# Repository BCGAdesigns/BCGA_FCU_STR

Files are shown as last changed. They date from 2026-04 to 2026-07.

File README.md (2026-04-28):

# BCGA FCU — Open-source HPA Fire Control Unit






> Open-source Fire Control Unit for airsoft HPA replicas. WiFi-native configuration, dual-solenoid support, 4 independent cycle timings, and Hall trigger with automatic EMI noise calibration — unique on the market.

> 🇧🇷 Leia em português: [LEIA-ME.md](LEIA-ME.md)

---

## What is the BCGA FCU?

The **BCGA FCU** is a digital Fire Control Unit for airsoft HPA (High Pressure Air) replicas, built around the ESP32-C3 SuperMini. It drives the solenoid(s) that replace the mechanical trigger of an HPA engine and lets you tune each phase of the firing cycle from any browser over WiFi — no app required.

Two hardware variants share the same firmware and web UI:

- **STR** (Starter) — perfboard / THT build, easily sourced components, ideal for makers and hobbyists learning HPA electronics.
- **PRO** — commercial SMD PCB with battery monitoring, LiPo kill latch, dedicated WiFi button and onboard buzzer.

Both variants support **S8PA** (1-solenoid engines — PolarStar JACK / F1, Wolverine INFERNO, GATE PULSAR S) and **D8PA** (2-solenoid engines — PolarStar F2 / Fusion Engine, GATE PULSAR D) per slot. You pick the engine type per profile — the UI adapts automatically.

This project is designed, manufactured and maintained by **[BCGA Airsoft](https://bcgaairsoft.com)** in Brazil. It is **open-source under GPL v3** — you can audit, modify, manufacture and sell, as long as derivatives keep the same license and credit the original project.

---

## Why BCGA FCU?

Compared to commercial FCUs (PolarStar REV3, Wolverine BLINC, GATE TITAN II, Gorilla FCU), the BCGA FCU has concrete advantages — and a few honest limitations. This section is factual; the full side-by-side tables are in [`MANUAL_EN.md`](MANUAL_EN.md) section 16.

### Where the BCGA FCU wins

1. **Native WiFi vs Bluetooth.** Configure from any browser on any device — iOS, Android, PC, Linux. No app install, no pairing, no vendor lock-in. TITAN II (BLE 5.2) and BLINC require proprietary apps.

2. **4 independent timings (DN/DR/DP/DB).** Each phase of the D8PA cycle has its own parameter. Feeding (DN), sealing (DR), FPS (DP) and post-shot debounce (DB) tune independently without trade-offs. Commercial FCUs top out at 3 user-facing timings (REV3 in dual-solenoid mode: dP/dN/dr) or a single dwell on single-solenoid setups — none expose a dedicated post-shot debounce.

3. **Automatic Hall trigger EMI noise calibration.** The only FCU on the market with a routine that fires the solenoids dry and measures the EMI kick on the ADC, widening the Hall deadband automatically. Eliminates ghost fires without sacrificing trigger sensitivity.

4. **3 complete independent slots.** Each slot stores everything — engine type, all 4 timings, selector config, individual Hall calibrations, flags. Switching slots = full game-profile switch.

5. **Open-source, GPL v3.** All code is public. Audit, modify, compile and flash without depending on proprietary firmware or a vendor app. TITAN II, BLINC and REV3 are fully closed.

6. **Hall trigger with 2-point calibration + automatic hysteresis.** Captures the exact fire point and computes a hysteresis band from real measurements — not fixed values. No mechanical potentiometer.

7. **3-position Hall selector.** SAFE/SEMI/FULL via a wear-free Hall sensor. Each position freely configurable to any mode (including BURST 2/3/4).

8. **Drastically lower BOM cost.** The STR can be built from easily sourced THT parts for a fraction of any commercial Bluetooth FCU.

9. **Live theoretical ROF in the UI.** The web panel shows maximum achievable ROF as you move the sliders — no chrono needed for a first-pass estimate.

10. **Per-slot S8PA/D8PA switching in software.** Each of the 3 slots independently stores the engine type — flip a slot between S8PA and D8PA directly from the web UI, no hardware change. Commercial FCUs that cover both architectures (TITAN II with PULSAR S/D, Gorilla) do it through separate dedicated cable harnesses per engine, not per-slot software switching.

### Honest limitations

- **No binary trigger.** Not implemented. Available on Wolverine BLINC, GATE TITAN II and Gorilla FCU.
- **No tournament lock with password.** Workaround: set Semi ROF high and ROF limit low before an event. Available on TITAN II (Expert) and Gorilla.
- **No automatic battery cut-off.** The firmware enters lockout mode (firing disabled, continuous beep) when the battery reaches critical level on the PRO variant, but you must physically disconnect the battery to preserve charge. The STR variant has no battery voltage read at all — use with caution on 2S/3S packs without external protection.
- **Battery drains while plugged.** The voltage regulators on the PRO board draw ~12-18mA continuously even when the ESP32 is sleeping. A 1000mAh pack will be fully discharged in 2-3 days if left connected. Always disconnect the battery between sessions.
- **First pull after deep sleep wakes via reboot.** After 60 min of idle, the next pull wakes the MCU through a full reboot — the **second** pull actually fires.

---

## Hardware specifications

| Item | Value |
|---|---|
| MCU | ESP32-C3 SuperMini |
| MOSFETs | IRLZ44NPBF (TO-220, THT) |
| Main connector | JST 8-pin (A1501WR-S-8P) — native to the D8PA ecosystem |
| Operating voltage | 7.4 V — 11.1 V (2S/3S LiPo) |
| Engine types | S8PA (1 solenoid) / D8PA (2 solenoids) |
| Fire modes | SAFE / SEMI / FULL / BURST 2 / BURST 3 / BURST 4 |
| Configuration | Web UI over WiFi AP (192.168.4.1) |
| Deep sleep | 60 min idle → ESP32 <10 µA, total board ~12-18 mA (regulators) |
| Inactivity alarm | 60 min idle → 6 cycles of 5min beep + 1h sleep, then permanent sleep |
| Battery management (PRO) | Lockout mode at critical voltage (no auto cut-off — physical disconnect required) |
| License | GPL v3 |

---

## Repository structure

```
BCGA_FCU_STR/
├── MotherBoard/              # Main board (MOBO) — BOM, CPL, GERBER, SCH, STEP
├── DaugtherBoard_BCGA/       # Daughterboard A — BCGA engine (S8PA or D8PA)
├── Gearbox_DaughterBoard/    # Daughterboard B — V2 standard (AEG conversion)
├── firmware/
│   ├── BCGA_FCU_STR/         # Arduino sketch — Starter variant
│   └── BCGA_FCU_PRO/         # Arduino sketch — Pro variant
├── MANUAL_EN.md / .pdf       # English manual (this README links here)
├── MANUAL_PT.md / .pdf       # Portuguese manual
├── README.md                 # English readme (this file)
├── LEIA-ME.md                # Portuguese readme
└── LICENSE                   # GPL v3
```

Each board folder contains: `BOM` (xlsx), `CPL` (xlsx), `GERBER` (zip), `SCH` (pdf) and `STEP` (3D model).

---

## How to use

1. Get the hardware — either buy a pre-assembled board from [bcgaairsoft.com/fcu/str](https://bcgaairsoft.com/fcu/str) / [fcu/pro](https://bcgaairsoft.com/fcu/pro), or clone this repo and build your own (see next section).
2. Flash the matching firmware from `firmware/BCGA_FCU_STR/` or `firmware/BCGA_FCU_PRO/` via the Arduino IDE. Target board: **ESP32-C3 Dev Module**, with **USB CDC On Boot = Enabled**.
3. On first boot, the FCU brings up a WiFi AP.
   - Default SSID: `BCGA_FCU_STR` or `BCGA_FCU_PRO`
   - Default password: `12345678`
4. Connect your phone/laptop to the AP. A captive page opens at `http://192.168.4.1`.
5. Configure the 3 slots: engine type (S8PA/D8PA), timings (DN/DR/DP/DB), selector, flags. The full tuning workflow is in [`MANUAL_EN.md`](MANUAL_EN.md).

To re-open the AP later:
- **STR** — hold the trigger for 5 s during the first 5 s after boot; OR pull the trigger 5 times in SAFE within 3 s.
- **PRO** — press the dedicated WiFi button; or use the same gestures as STR.

The AP shuts off automatically after 10 min of web inactivity.

---

## Build your own

1. Upload the chosen board's `GERBER` zip to a PCB fab (JLCPCB, PCBWay, etc.).
2. Order the components from the matching `BOM`. Most parts are available on [LCSC](https://www.lcsc.com/).
3. Solder following the `SCH` (schematic).
4. Flash the firmware from `firmware/BCGA_FCU_{STR,PRO}/` via the Arduino IDE.
5. Calibrate the Hall trigger and selector from the web UI (sections 7 and 8 of the manual).

> ⚠️ **STR** requires basic THT soldering skills (TO-220 MOSFETs, through-hole headers). **PRO** requires basic SMD soldering skills. For a plug-and-play board, buy the pre-assembled version at [bcgaairsoft.com](https://bcgaairsoft.com).

---

## License

[**GPL v3**](LICENSE). You can manufacture, modify, sell and distribute freely, as long as derivatives keep the same license and credit the original project. Closed-source forks are not permitted.

---

## Links

- **Product pages:** [bcgaairsoft.com/fcu/str](https://bcgaairsoft.com/fcu/str) · [bcgaairsoft.com/fcu/pro](https://bcgaairsoft.com/fcu/pro)
- **Main site:** [bcgaairsoft.com](https://bcgaairsoft.com)
- **User manual (English):** [MANUAL_EN.md](MANUAL_EN.md) · [PDF](MANUAL_EN.pdf)
- **User manual (Portuguese):** [MANUAL_PT.md](MANUAL_PT.md) · [PDF](MANUAL_PT.pdf)
- **Issues and support:** [GitHub Issues](https://github.com/BCGAdesigns/BCGA_FCU_STR/issues)

---

**BCGA Airsoft** — [bcgaairsoft.com](https://bcgaairsoft.com)

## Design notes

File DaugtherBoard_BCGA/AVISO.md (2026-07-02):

# AVISO / NOTICE

PT: Erro encontrado em uma trilha da PCB. Correção em andamento. Arquivos atualizados (Gerber, BOM, CPL, esquematico, STEP) serao enviados em breve. Nao fabrique nem monte com os arquivos atuais.

EN: Error found in one PCB trace. Fix in progress. Updated files (Gerber, BOM, CPL, schematic, STEP) coming soon. Do not fabricate or assemble with current files.

Data / Date: 2026-07-01

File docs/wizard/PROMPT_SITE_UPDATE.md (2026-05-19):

# Prompt para Claude Code — atualizar o wizard em bcgaairsoft.com

Cole o conteúdo abaixo numa nova sessão do Claude Code aberta no repositório do site (`~/ClaudeCode/projeto/bcgaairsoft/bcgaairsoft`). Ele descreve o estado atual do firmware da BCGA FCU, as mudanças recentes que precisam refletir no wizard online, e a nova tela inicial de 3 menus.

---

## Contexto

Você está trabalhando no site React da BCGA Airsoft (`bcgaairsoft.com`). O site hospeda um **Setup Wizard** público que ajuda o usuário a planejar a configuração da FCU **antes** de flashar e tunar no airsoft.

A FCU em si tem o repositório separado em `~/ClaudeCode/projeto/bcgaairsoft/BCGA_FCU_STR`. Lá existem dois pontos de referência que valem consultar:

- `docs/wizard/index.html` + `wizard.css` + `wizard.js` — versão standalone original do wizard (5 steps), serve de base visual e estrutural.
- `firmware/web_ui_dev/index_str.html`, `index_pro.html`, `style.css`, `app.js` — UI **runtime** servida pelo ESP no AP (estado atual após várias rodadas de iteração). É a fonte de verdade dos campos/labels/help texts.

O wizard online deve ficar **alinhado com o runtime** (mesmas siglas, mesmos defaults, mesmas faixas), mas mantém o foco em ensinar/planejar — ele não escreve no ESP.

## Tarefa

1. **Encontrar o wizard atual no site** (provavelmente em `src/pages/wizard` ou similar — explore antes de tocar).
2. **Reescrever a tela inicial** para 3 menus (detalhe abaixo).
3. **Reaproveitar o wizard de configuração existente** dentro do menu "Quero configurar do zero".
4. **Adicionar dois novos modos** ("Aprender" e "Resolver problema").
5. **Atualizar todos os campos, defaults, faixas e textos de ajuda** para casar com o estado atual do firmware (lista completa abaixo).

## Tela inicial — 3 menus

Depois do header (logo + nome BCGA FCU · Setup Wizard + toggle PT/EN), o usuário vê 3 cards grandes clicáveis:

1. **Quero apenas aprender** → entra no modo educacional. Tour guiado explicando uma a uma cada função da FCU. Sem perguntas, só conteúdo + navegação Próximo/Anterior. Lista de tópicos sugerida na seção "Modo Aprender" abaixo.

2. **Quero configurar do zero** → entra no wizard atual de 5 steps. Esta é a versão hoje em produção (engine pick → FPS alvo → FPS atingido? → fine-tune → summary). Mantenha o fluxo, mas atualize os campos/labels/textos de ajuda conforme a seção "Mudanças no firmware" abaixo.

3. **Quero resolver um problema** → modo troubleshooting. Usuário descreve o sintoma (input de texto livre OU lista de sintomas comuns clicáveis — escolha o que fizer mais sentido para o site). O wizard responde com diagnóstico + onde mexer. Catálogo de sintomas → soluções na seção "Modo Resolver problema" abaixo.

Adicione um botão de "Voltar ao início" persistente em qualquer ponto dos 3 fluxos.

## Mudanças no firmware desde a última versão do wizard

Atualize TODOS os pontos do wizard atual (modo "Configurar do zero") para refletir o que segue:

### Renomeação de seções

| Antes | Agora |
|---|---|
| "Tipo de disparo" | **Engine** |
| "Entrada" | **Funções** |
| (não existia) | **Avançado** |
| (não existia) | **Estatísticas** |

### Cards do Engine

- "Single Solenoid S8PA" — subtítulo "1 solenoid (Jack, Backdraft)"
- "Dual Solenoid D8PA" — subtítulo "2 solenoids (F2, Pulsar)"

### Defaults validados em campo (use estes nos exemplos do wizard)

- DN = 24 ms (antes 18)
- DR = 24 ms (antes 26)
- DP = 24 ms (antes 80; o "max-tune-down" foi abandonado)
- DB = **5 unidades** (= 0,5 ms; faixa nova: 5–150 unidades = 0,5–15 ms)
- IS = 30 s (antes 60)
- IP = 1 multiplicador (NOVO conceito — explicado abaixo)

### Faixas atuais

| Campo | Faixa | Unidade | Default |
|---|---|---|---|
| DN | 2–80 | ms | 24 |
| DR | 2–80 | ms | 24 |
| DP | 2–80 | ms | 24 |
| DB | 5–150 | unidades de 0,1 ms (= 0,5–15 ms) | 5 |
| ROF max | 0–50 | rps (0 = sem limite) | 0 |
| Semi Max ROF | 0–500 | ms | 0 |
| IS | 0–600 | segundos | 30 |
| IP | 0–5 | multiplicador de DP | 1 |

### Anti-stiction (NOVO — IS + IP)

Conceito que NÃO existia no wizard antigo. Adicione um bloco explicando:

- **Stiction** = o o-ring do poppet "gruda" depois da arma ficar parada por um tempo. Resultado: primeiro tiro depois de tempo parado sai com FPS baixo / sem cadência.
- **IS (Inter-Stiction Idle)** — tempo em segundos de inatividade até o boost ser armado. Padrão 30 s.
- **IP (Inter-Stiction Pulse)** — multiplicador de DP. Cada incremento adiciona um DP inteiro ao próximo tiro pós-idle.
  - DP = 24 ms, IP = 1 → primeiro tiro pós-idle dispara com DP = 48 ms (24+24)
  - DP = 24 ms, IP = 2 → primeiro tiro pós-idle dispara com DP = 72 ms (24+24+24)
  - IP = 0 → desabilitado.
- **Quando ajustar:** se o primeiro tiro depois de ficar 30+ s parado sair fraco, suba o IP em 1 e teste no chrono. Tiros subsequentes voltam ao DP normal automaticamente.

### Tipo de seletor (Selector input)

Antes só dava pra mexer em selPos1/2/3. Agora a UI tem um dropdown explícito **"Selector input: Microswitch / Hall (analog)"**, espelhando o do gatilho. A seção de Calibração do Seletor só aparece quando Hall é escolhido. 3-pos continua forçando Hall (e trava o dropdown).

### "Inverter gatilho" sumiu

Campo `invertTrig` continua no firmware mas **não aparece mais na UI**. Não mencione no wizard.

### Idioma padrão = EN

Page-load default agora é EN (antes era BR). Ainda tem toggle BR/EN. Mantenha o toggle no wizard online.

### Estatísticas (somente runtime — NÃO precisa no wizard online)

A FCU agora exibe stats em tempo real (Tiros sessão, Tiros total, Bateria no PRO, próxima lubrificação a cada 10k tiros). É só pra você saber que existe — não é parte do fluxo de planejamento.

### Config LOCK e Factory Reset (somente runtime)

Mesma situação. A FCU tem agora trava de configuração via senha + reset de fábrica por gesture (gatilho 30 s no boot, no PRO + botão WiFi). Mencione brevemente no modo "Aprender" mas não no fluxo de configuração.

## Modo Aprender — sugestão de capítulos

Cada capítulo é uma página/card com explicação curta (~150 palavras), 1 imagem ou diagrama opcional, e botões Anterior/Próximo:

1. **O que é uma FCU** — diferença entre AEG eletrônica e HPA, qual papel a FCU faz no airsoft HPA.
2. **Engines: S8PA vs D8PA** — single vs dual solenoid, exemplos (Jack/Backdraft vs F2/Pulsar/Wolverine), implicação prática (D8PA tem nozzle independente, alimentação mais consistente).
3. **Ciclo de disparo D8PA** — animação ou diagrama: pulso SOL2 (DN) → espera (DR) → pulso SOL1 (DP) → espera pós-tiro (DB) → repete.
4. **Ciclo de disparo S8PA** — só pulso SOL1 (DP) → espera (DR) → repete. DN e DB inativos.
5. **DN — Nozzle Dwell** — para que serve, sintomas de DN curto (falha de alimentação) vs longo (desperdício de gás). Faixa, padrão.
6. **DR — Dwell Rest** — em D8PA: espera entre nozzle e poppet pra mola vedar o bucking. Em S8PA: descanso entre tiros. Faixa, padrão.
7. **DP — Dwell Poppet** — duração do pulso de tiro. Sintomas: DP curto = FPS baixo; DP longo = desperdício de gás + risco de tiro duplo. Tunar no chrono.
8. **DB — Trigger Debounce** — pausa entre ciclos pra BB sair do cano antes do próximo tiro (D8PA). Faixa nova 5–150 unidades de 0,1 ms.
9. **ROF max e ROF teórico** — diferença entre limite e teórico, como o teórico é calculado.
10. **Anti-stiction (IS + IP)** — bloco completo conforme descrito acima.
11. **Seletor: Pos1/Pos2/Pos3 e modos de fogo** — Safe/Semi/Full/Burst2/3/4.
12. **Microswitch vs Hall** — quando escolher cada um, calibração necessária para Hall.
13. **Calibração Hall** — fluxo de noise + posições (gatilho solto/pressionado, ou 3 posições do seletor).
14. **Modo silencioso e MOSFET swap** — quando usar.
15. **Config LOCK e Factory Reset por gesture** — como travar configuração pra evitar mexida acidental, como recuperar se esquecer (gesto físico no boot).
16. **Estatísticas em tempo real** — bateria, tiros, próxima lubrificação a cada 10k.

Pode reagrupar ou cortar capítulos conforme fizer sentido visualmente. Mantenha foco em "tuning-first" — toda explicação de timing leva ao "o que aumentar/diminuir pra qual sintoma".

## Modo Resolver problema — catálogo de sintomas

Sugestão de input: lista de sintomas clicáveis (mais robusto que parsing de texto livre numa primeira versão). Cada item leva a uma tela com:
- Diagnóstico provável
- Setting a verificar
- Range/passo sugerido pra ajuste
- Avisos

Catálogo mínimo:

| Sintoma | Causa provável | Onde mexer |
|---|---|---|
| Arma não dispara | Bateria descarregada / seletor em SAFE / fire mode SAFE em todas as posições | Conferir bateria · Verificar selPos1/2/3 |
| FPS baixo geral | DP curto / regulador baixo / vazamento na engine | Subir DP (testar no chrono) · Conferir pressão · Inspecionar o-rings |
| Primeiro tiro fraco após arma parada | Stiction do o-ring do poppet | **Habilitar IP (=1) com IS=30s**; subir IP até estabilizar |
| FPS inconsistente tiro a tiro | Vazamento intermitente / regulador instável / BB mass inconsistente | Trocar BBs · Inspecionar regulador · Conferir vazamentos |
| Falha de alimentação (BB não chega) | DN muito curto (D8PA) / nozzle gasto / mola fraca | Subir DN · Trocar nozzle · Trocar mola da torre |
| Cadência muito alta (incontrolável) | DR curto / DB curto / sem ROF cap | Subir DR · Subir DB · Definir ROF max |
| Cadência muito baixa | Soma de timings alta | Reduzir DN, DR, DB pelo menor valor que ainda funcione |
| Tiros duplos em SEMI | Trigger ricochete / Hall mal calibrado | Habilitar Semi Max ROF (tente 100ms) · Recalibrar Hall com noise |
| Cadência sobe e desce em FULL | ROF cap zerado + bateria caindo | Definir ROF max abaixo do pico real |
| Esqueci a senha do Config LOCK | Sem recuperação digital | Factory reset por gesture: gatilho 30s no boot (STR) ou gatilho + botão WiFi 30s (PRO) |
| Seletor Hall lê posição errada | Calibração de seletor desatualizada | Calibração do seletor (3 posições) — fluxo Hall |
| Gatilho Hall dispara sozinho | Ruído eletromagnético do solenoide | Calibração de ruído ANTES da calibração do gatilho |

Adicione mais conforme fizer sentido. Para cada solução, link pra explicação no modo "Aprender" se houver.

## Estilo

- Mantenha a paleta atual do site bcgaairsoft.com (memory note: "site is the visual source of truth — pull palette/fonts from there"). Não invente cores novas.
- O wizard runtime usa accent verde (`#8aab47` STR / `#00bcd4` PRO). O site provavelmente já tem palette própria — siga o do site.
- Toggle PT/EN persistente no header. Idioma default = EN.

## Entregáveis

1. Tela inicial 3-menus integrada ao wizard.
2. Modo "Aprender" com pelo menos 12 dos 16 capítulos sugeridos.
3. Modo "Resolver problema" com pelo menos 8 dos 12 sintomas do catálogo.
4. Modo "Configurar do zero" atualizado com todos os campos/defaults/textos novos.
5. README curto explicando como rodar localmente e onde editar conteúdo (capítulos do Aprender e catálogo de Resolver), porque eles vão crescer.

## O que NÃO fazer

- Não copiar o `firmware/web_ui_dev/` direto — aquilo é UI de configuração runtime, este wizard tem propósito diferente (pré-flash, educacional).
- Não inventar campos que não existam no firmware.
- Não escrever em `firmware/` neste repo — você está no repo do site.
- Não traduzir nomes técnicos consagrados (DN, DR, DP, DB, IS, IP, S8PA, D8PA, F2, Jack, Pulsar) — só os textos de ajuda em volta.

Quando terminar, mostre URL local pra eu testar e abra um PR descrevendo as mudanças.

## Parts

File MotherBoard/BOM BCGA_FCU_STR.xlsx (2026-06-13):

No. | Quantity | Comment | Designator | Footprint | Value | Manufacturer Part | Manufacturer | Supplier Part | Supplier
1 | 2 | 100nF | C1,C2 | CAP-TH_L5.0-W2.5-P5.00-D1.0 | 100nF | CC1H104MC1FD3F6C10MF | Dersonic(德尔创) | C254085 | LCSC
2 | 2 | 470uF | C3,C4 | CAP-TH_BD10.0-P5.00-D1.0-FD | 470uF | ERS1VM471G16OT | AISHI(艾华集团) | C106703 | LCSC
3 | 2 | 100nF | C5,C6 | CAP-TH_L5.8-W3.6-P5.0-D0.6 | 100nF | 178MU0002 | KNSCHA(科尼盛) | C5632426 | LCSC
4 | 1 | A1501WR-S-8P | CN1 | CONN-TH_A1501WR-S-8P |  | A1501WR-S-8P | CJT(长江连接器) | C225173 | LCSC
5 | 2 | 1N5819 | D1,D2 | DO-41_BD2.4-L4.7-P8.70-D0.9-RD |  | 1N5819 | DOWO(东沃) | C27636129 | LCSC
6 | 2 | IRLZ44NPBF-VB | Q2,Q3 | TO-220-3_L10.0-W4.5-P2.54-L-2 |  | IRLZ44NPBF-VB | VBsemi(微碧半导体) | C20755022 | LCSC
7 | 2 | 10kΩ | R1,R2 | RES-TH_BD2.3-L6.5-P10.50-D0.5 | 10kΩ | MF1/4W-10KΩ±1% T | CCO(千志电子) | C119347 | LCSC
8 | 2 | 100Ω | R3,R4 | RES-TH_BD2.3-L6.5-P10.50-D0.5 | 100Ω | MF1/4W-100Ω±1% T | CCO(千志电子) | C119304 | LCSC
9 | 2 | 1kΩ | R5,R6 | RES-TH_BD2.3-L6.5-P10.50-D0.5 | 1kΩ | MF1/4W-1KΩ±1%T52 | 华星机电 | C713997 | LCSC
10 | 2 | Test-Point | TP1,TP2 | Test-Point-0.5mm
11 | 1 | Mini DC-DC Boost Step Up Converter | U1 | MINI DC-DC BOOST STEP UP CONVERTER |  |  |  |  | LCSC
12 | 1 | ESP32-C3 OLED | U6 | ESP32-C3 OLED

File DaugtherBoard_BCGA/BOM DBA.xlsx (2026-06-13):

No. | Quantity | Comment | Designator | Footprint | Value | Manufacturer Part | Manufacturer | Supplier Part | Supplier
1 | 2 | 100nF | C1,C2 | C0603 | 100nF | CC0603KRX7R9BB104 | YAGEO(国巨) | C14663 | LCSC
2 | 1 | A1501WR-S-8P | CN1 | CONN-TH_A1501WR-S-8P |  | A1501WR-S-8P | CJT(长江连接器) | C225173 | LCSC
3 | 3 | S2B-ZR-SM2-TF(LF)(SN) | CN6,CN10,CN11 | CONN-SMD_2P-P1.50_S2B-ZR-SM2-TF-LF-SN |  | S2B-ZR-SM2-TF(LF)(SN) | JST | C5306678 | LCSC
4 | 2 | 1kΩ | R1,R2 | R1206 | 1kΩ | 1206W4F1001T5E | UNI-ROYAL(厚声) | C4410 | LCSC
5 | 2 | SS39ET | U1,U2 | SOT-23-3_L2.9-W1.3-P1.90-LS2.4-BR |  | SS39ET | Honeywell(霍尼韦尔) | C126669 | LCSC

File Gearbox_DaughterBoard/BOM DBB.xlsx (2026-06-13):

No. | Quantity | Comment | Designator | Footprint | Value | Manufacturer Part | Manufacturer | Supplier Part | Supplier
1 | 2 | 100nF | C2,C3 | C0402 | 100nF | CL05B104KB54PNC | SAMSUNG(三星) | C307331 | LCSC
2 | 4 | S2B-ZR-SM2-TF(LF)(SN) | CN6,CN9,CN10,CN11 | CONN-SMD_2P-P1.50_S2B-ZR-SM2-TF-LF-SN |  | S2B-ZR-SM2-TF(LF)(SN) | JST | C5306678 | LCSC
3 | 1 | A1501WR-S-8P | CN12 | CONN-TH_A1501WR-S-8P |  | A1501WR-S-8P | CJT(长江连接器) | C225173 | LCSC
4 | 2 | 1kΩ | R2,R3 | R0402 | 1kΩ | 0402WGF1001TCE | UNI-ROYAL(厚声) | C11702 | LCSC
5 | 2 | SS39ET | U2,U3 | SOT-23-3_L2.9-W1.3-P1.90-LS2.4-BR |  | SS39ET | Honeywell(霍尼韦尔) | C126669 | LCSC

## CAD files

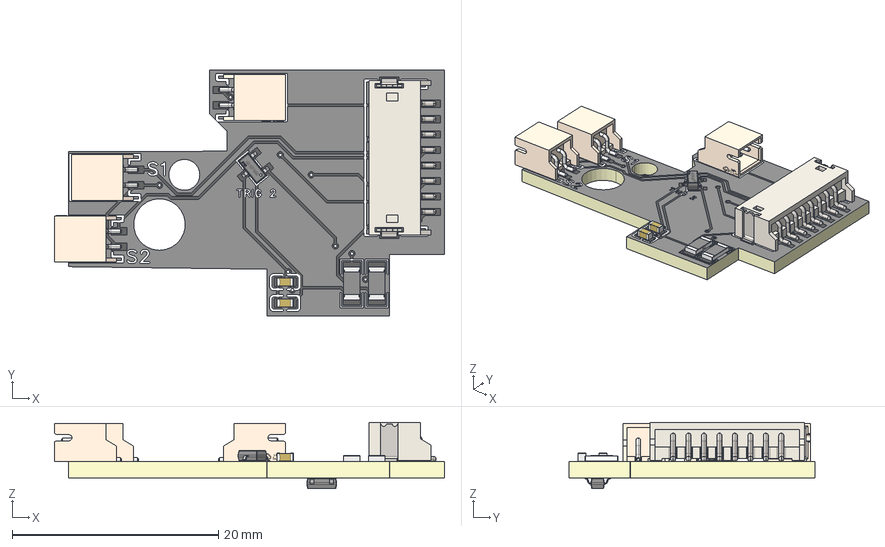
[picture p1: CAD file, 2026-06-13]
Assembly_STEP/DBA.step
37.8 x 23.9 x 6.45 mm
Board~A52b
TopCopper~A52b x 19
BottomCopper~A52b x 10
TopSilkscreen~A52b x 46
BottomSilkscreen~A52b x 89
TopFpcStiffener~A52b
BottomFpcStiffener~A52b
SOT-23-3_L2.9-W1.3-P1.90-LS2.4-BR~SOT-23-3P_ L2.9-W1.3-H1.0-LS2.4-P0.95~A52b x 2
C0603~C0603_L1.6-W0.8-H0.8~A52b x 2
R1206~R1206_L3.2-W1.6-H0.6~A52b x 2
CONN-TH_A1501WR-S-8P~CONN-TH_A1501WR-S-8P~A52b
CONN-SMD_2P-P1.50_S2B-ZR-SM2-TF-LF-SN~CONN-SMD_2P-P1.50_ S2B-ZR-SM2-TF-LF-SN~A52b x 3

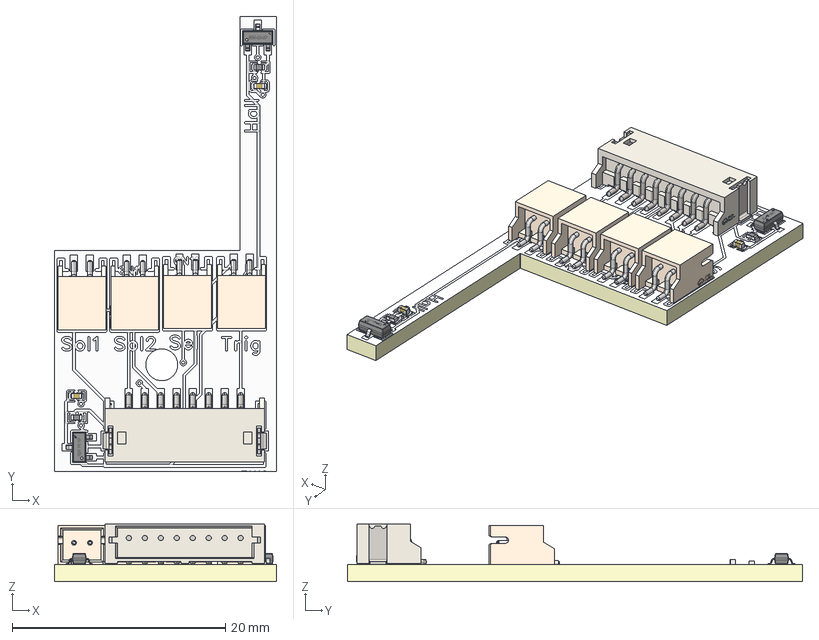
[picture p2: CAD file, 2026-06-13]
Gearbox_DaughterBoard/STEP DBB.step
20.9 x 42.7 x 5.41 mm
Board~KRs3
TopCopper~KRs3 x 19
BottomCopper~KRs3 x 5
TopSilkscreen~KRs3 x 71
BottomSilkscreen~KRs3
TopFpcStiffener~KRs3
BottomFpcStiffener~KRs3
C0402~C0402_L1.0-W0.5-H0.5~KRs3 x 2
CONN-SMD_2P-P1.50_S2B-ZR-SM2-TF-LF-SN~CONN-SMD_2P-P1.50_ S2B-ZR-SM2-TF-LF-SN~KRs3 x 4
CONN-TH_A1501WR-S-8P~CONN-TH_A1501WR-S-8P~KRs3
SOT-23-3_L2.9-W1.3-P1.90-LS2.4-BR~SOT-23-3P_ L2.9-W1.3-H1.0-LS2.4-P0.95~KRs3 x 2
R0402~R0402_L1.0-W0.5-H0.4~KRs3 x 2

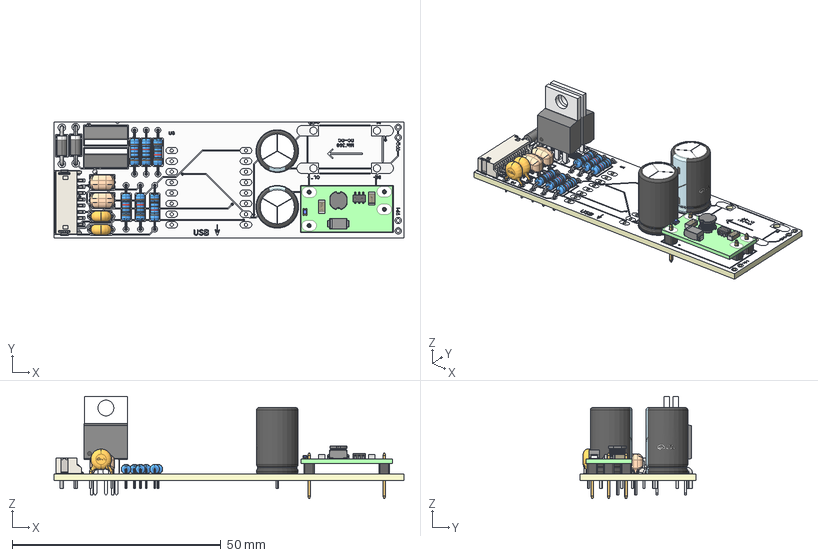
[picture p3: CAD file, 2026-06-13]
MotherBoard/STEP BCGA_FCU_STR.step
83.8 x 27.8 x 24.5 mm
Board~LMB1
TopCopper~LMB1 x 54
BottomCopper~LMB1 x 41
TopSilkscreen~LMB1 x 134
BottomSilkscreen~LMB1 x 34
TopFpcStiffener~LMB1
BottomFpcStiffener~LMB1
RES-TH_BD2.3-L6.5-P10.50-D0.5~RES-TH_D2.3-L6.5-P10.50~QHUY x 6
CONN-TH_A1501WR-S-8P~CONN-TH_A1501WR-S-8P~HQcQ
CAP-TH_BD10.0-P5.00-D1.0-FD~CAP-TH_D10.0-H16.0-P5.00~eAUI x 2
DO-41_BD2.4-L4.7-P8.70-D0.9-RD~DO-41_D2.4-L4.7-P8.70~po2f x 2
TO-220-3_L10.0-W4.5-P2.54-L-2~TO-220-3_L10.0-W4.5-P2.54-L-2~1yOL x 2
CAP-TH_L5.0-W2.5-P5.00-D1.0~CAP-TH_BD5.0-W2.5-P5.08~cXeb x 2
CAP-TH_L5.8-W3.6-P5.0-D0.6~CAP-TH_L5.8-W3.6-P5.0-D0.6~0Ine x 2
MINI DC-DC BOOST STEP UP CONVERTER~mini_dc_dc_PIN~Bhf9 x 11

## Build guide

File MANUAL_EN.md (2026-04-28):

# BCGA FCU — User Manual (EN)

Open-source firmware for the ESP32-C3 SuperMini. Two variants: **STR** (Starter, perfboard) and **PRO** (commercial product). The web UI and firing logic are nearly identical — differences are listed at the end.

This manual is practical: each section leads with **what to tweak to get what result**.

> 🇧🇷 Versão em português: [MANUAL_PT.md](./MANUAL_PT.md)

---

## Table of contents

1. [Understand the FCU in 1 minute](#1-understand-the-fcu-in-1-minute)
2. [Quick start — reach target FPS first](#2-quick-start--reach-target-fps-first)
3. [The 4 timings — tuning guide](#3-the-4-timings--tuning-guide)
4. [Recommended tuning workflow](#4-recommended-tuning-workflow)
5. [Firing type: S8PA vs D8PA](#5-firing-type-s8pa-vs-d8pa)
6. [Selector — 2 or 3 positions](#6-selector--2-or-3-positions)
7. [Hall trigger — step-by-step calibration](#7-hall-trigger--step-by-step-calibration)
8. [Hall selector — step-by-step calibration](#8-hall-selector--step-by-step-calibration)
9. [First use and web panel access](#9-first-use-and-web-panel-access)
10. [Slots](#10-slots)
11. [Useful flags (invert trigger, swap MOS, silent)](#11-useful-flags)
12. [Limit rate of fire (ROF limit and Semi ROF)](#12-limit-rate-of-fire)
13. [Diagnostics and WiFi](#13-diagnostics-and-wifi)
14. [Deep sleep, inactivity alarm and debug mode](#14-deep-sleep-inactivity-alarm-and-debug-mode)
15. [STR vs PRO differences](#15-str-vs-pro-differences)
16. [BCGA FCU vs commercial FCUs](#16-bcga-fcu-vs-commercial-fcus)

---

## 1. Understand the FCU in 1 minute

The FCU drives **1 or 2 solenoids** that replace the mechanical trigger of an HPA engine. For each shot it sends electrically calibrated pulses to the solenoids, in the correct order, with the correct waits between them. Tuning = adjusting those pulses for your specific setup (pressure, bucking, BB mass).

- **S8PA** (1 solenoid): PolarStar JACK / F1, Wolverine INFERNO, GATE PULSAR S, or any other 1-solenoid HPA engine. Only the poppet is driven.
- **D8PA** (2 solenoids): PolarStar F2 / Fusion Engine, GATE PULSAR D, or any other 2-solenoid HPA engine. Nozzle and poppet driven separately.

---

## 2. Quick start — reach target FPS first

New to the BCGA FCU? Before anything else, hit your target FPS. The rest of the tuning only makes sense once the chrono is where you want it. The 4 timings (DN/DR/DP/DB) are fully explained in section 3 — for this first pass you only touch **DP** (the poppet dwell slider) and the regulator.

1. **Set the regulator to 100 psi.** Default starting pressure for most D8PA setups.
2. **Keep the default timings** (`DN=18 / DR=26 / DP=25 / DB=100`). They ship loaded.
3. **Fire over a chrono.** Is the FPS (or joule) on target?
   - **Yes** → skip straight to section 4 and tune feeding, sealing and accuracy.
   - **No, too low** → step 4.
4. **Push DP to the slider maximum** (80 ms). Chrono again.
   - **FPS jumped to target** → lower DP step-by-step until FPS starts to drop, then add 1–2 ms back. That's your minimum efficient DP. Go to section 4.
   - **FPS still below target** → step 5.
5. **Raise the regulator to 110 psi.** Chrono again.
   - **On target** → lower DP until you find the minimum that holds target FPS. Go to section 4.
   - **Still low** → raise to **120 psi** and chrono again.
6. Once target FPS is stable, **go to section 4** and tune DN (feeding), DR (sealing) and DB (accuracy) in that order.

> **Principle:** FPS is driven mostly by **air pressure × DP**. The other 3 timings shape how the cycle *behaves* (feeding, sealing, accuracy, ROF) — they don't add FPS. Nail FPS first with DP/pressure, tune everything else after.

---

## 3. The 4 timings — tuning guide

The FCU exposes **4 independent timings** that map directly to each physical phase of the firing cycle: **DN**, **DR**, **DP**, **DB**. The page shows the theoretical ROF live as you move the sliders.

> **Note on units:** DN, DR and DP are in **milliseconds** (range 2–80 ms). **DB** (Trigger Debounce) uses **units** — 1 unit = 0.1 ms, range 20–800 units (= 2–80 ms). This aligns DB with the firmware's internal 0.1 ms timing resolution.

### DN — Nozzle Dwell (D8PA only)

Length of the **nozzle (SOL2)** pulse. This is how long the nozzle stays open for the BB to drop into the chamber.

| If DN increases | If DN decreases |
|---|---|
| ✅ easier feeding (heavy BBs, low pressure, cold shot) | ✅ saves air, prevents double-feed |
| ❌ **risk of double-feed** (2 BBs drop) | ❌ empty shots / inconsistent feeding if the return spring is slow |
| ❌ more nozzle wear | ❌ may not seal before DP fires |

**Rule of thumb:** decrease DN until you start getting empty shots, then add 1–2 ms margin.

### DR — Return / Rest

- **In D8PA**: wait between the nozzle pulse and the poppet pulse. Time for the nozzle to return and the **bucking to seal on the BB**.
- **In S8PA**: inter-shot rest.

| If DR increases | If DR decreases |
|---|---|
| ✅ consistent sealing → **stable FPS** | ✅ **higher ROF** |
| ✅ less shot-to-shot spread | ❌ poppet fires before seal → weak shot / low and variable FPS |
| ❌ lower ROF | ❌ BBs dropping past an open nozzle = double / bad pickup |

**Rule of thumb:** raise DR until the chrono stops oscillating under fast SEMI.

### DP — Poppet Dwell (the shot)

Length of the **poppet (SOL1)** pulse. This is how long air can flow through the nozzle pushing the BB.

| If DP increases | If DP decreases |
|---|---|
| ✅ **higher FPS** (more air behind the BB) | ✅ saves air (more shots per bottle/mag) |
| ❌ air waste after BB has left | ✅ higher ROF (valve closes fast) |
| ❌ may delay poppet recycle | ❌ **FPS below target**, weak shot |

**Rule of thumb:** with a chrono, tune DP up to your target FPS. Anything more just wastes air.

### DB — Trigger Debounce (D8PA only)

Wait after the poppet closes, before the trigger can re-arm the next cycle. Physically, this is the time needed for the **BB to clear the barrel** and the bucking to recover.

**Unit:** 1 unit = 0.1 ms. **Range:** 20–800 units (2–80 ms). **Default:** 100 units (10 ms).

| Units | Equivalent ms |
|---:|---:|
| 20  | 2.0  |
| 50  | 5.0  |
| 100 | 10.0 |
| 200 | 20.0 |
| 800 | 80.0 |

| If DB increases | If DB decreases |
|---|---|
| ✅ **better accuracy** (BB has left before the next nozzle opens) | ✅ **higher ROF** |
| ✅ bucking recovers undisturbed | ❌ BB still in the barrel when the next nozzle pulses → **flyers / inconsistent FPS** |
| ❌ lower ROF | ❌ reduced bucking life |

**Rule of thumb:** full-auto on a 20 m target. If flyers appear, bump DB by 20 units (2 ms) at a time.

### Defaults (generic D8PA, 110 psi, 0.28 g BB)

```
DN = 18 ms    DR = 26 ms    DP = 25 ms    DB = 100 units (10 ms)
```

Safe starting point. Tune from there.

---

## 4. Recommended tuning workflow

Follow this order — each step depends on the previous one being stable. Assumes you already hit your target FPS per section 2.

1. **Feeding (DN)** — slow SEMI. Lower DN until you get empty shots. Add 2 ms back.
2. **Sealing (DR)** — fast SEMI. If chrono wobbles, raise DR 2 ms at a time.
3. **FPS (DP)** — with chrono, raise DP to hit target FPS. Don't go higher.
4. **Accuracy (DB, D8PA only)** — full-auto on a target. If flyers, raise DB by 20 units.
5. **Cadence (ROF limit)** — optional. Caps maximum ROF independently of timings.
6. **Anti-spam (Semi ROF)** — optional. Minimum time between SEMI pulls.

> ⚠️ Always verify with a chrono. FPS drifts with bottle temperature / air level.

---

## 5. Firing type: S8PA vs D8PA

Chosen per slot in the first section of the panel.

- **S8PA** — only the poppet is pulsed. Cycle: `DP → DR → repeat`. Use with PolarStar JACK / F1, Wolverine INFERNO, GATE PULSAR S, or any 1-solenoid HPA engine. The DN, DB, MOS swap fields and the SOL 2 test button are hidden.
- **D8PA** — separate nozzle + poppet. Cycle: `DN → DR → DP → DB → repeat`. Use with PolarStar F2 / Fusion Engine, GATE PULSAR D, or any 2-solenoid system.

---

## 6. Selector — 2 or 3 positions

Enabling "3 positions" **requires a Hall selector** (a microswitch can only distinguish 2 states). Enabling it reveals Pos 3 in the UI.

Each position is assigned to a mode **independently**:

| Mode | Behavior |
|---|---|
| **SAFE** | Trigger pull does nothing. Mode-change beeps still play. |
| **SEMI** | One shot per pull. Honors Semi ROF if configured. |
| **FULL** | Fires while the trigger is held. |
| **BURST 2 / 3 / 4** | Fires 2/3/4 rounds per pull, even if trigger is released. |

Common examples:
- **2-position**: Pos 1 = SAFE, Pos 2 = SEMI *(or Pos 1 = SEMI, Pos 2 = FULL)*
- **3-position**: Pos 1 = SAFE, Pos 2 = SEMI, Pos 3 = FULL

---

## 7. Hall trigger — step-by-step calibration

Use Hall for a **wear-free trigger** with an **adjustable fire point**.

**Expected hardware:** linear Hall sensor (DRV5055 or similar) powered from 3.3 V, output wired to **PIN_TRIG** (GPIO 0 on both variants). Magnet on the trigger lever.

### 7.1 Mode selection

**Input** section → "Trigger type" → **Hall** → **Save**.

### 7.2 Quick calibration (single-point)

Covers most cases — 30 seconds.

1. In the **Sensitivity** section, pull the trigger **to the exact fire point you want** and hold.
2. Click **Capture point**.
3. The FCU reads the ADC and builds a symmetric hysteresis band around that value.
4. Save the slot.

Fires before reaching the point → capture at a deeper pull.
Won't fire even at full pull → capture at a shallower pull.

### 7.3 Full calibration (maximum precision)

In the **Trigger calibration** section:

1. **Noise calibration**
   - FCU fires **a full cycle without a BB** sampling the ADC during the solenoid pulses.
   - Measures EMI noise and **widens the deadband automatically**.
   - Prevents ghost fires caused by the MOSFETs' own switching kick.
   - ⚠️ **Run with the gearbox assembled and bottle connected** — noise depends on physical setup.

2. **Capture Released**
   - Trigger fully released → **Capture Released**.

3. **Capture Pressed**
   - Trigger fully pulled → **Capture Pressed**.

4. FCU computes a central threshold and a hysteresis band based on both points + measured noise.

5. **Save slot**.

### Hall trigger tuning

| Symptom | Likely cause | Fix |
|---|---|---|
| Ghost fires | Solenoid EMI bigger than deadband | Re-run noise calibration |
| Fires before fire point | Threshold too low | Recapture at a deeper pull point |
| Won't fire even at full pull | Threshold too high or magnet too far | Recapture, or move magnet closer |
| Flickers at threshold | Hysteresis band too narrow | Use full calibration instead of single-point |

---

## 8. Hall selector — step-by-step calibration

A Hall selector enables **3 physical positions** (classic SAFE/SEMI/FULL) or just more reliable 2-position reading.

**Expected hardware:** linear Hall sensor on the gearbox body, magnet on the selector plate. Output wired to **PIN_SEL** (GPIO 1).

### 8.1 Mode selection

**Input** section → "Selector type" → **Hall** → check "3 positions" if applicable → **Save**.

### 8.2 Calibration

**Selector calibration** section:

1. **Noise calibration** (optional but recommended) — same principle as the trigger.
2. Rotate selector to **Pos 1** → **Capture Pos 1**.
3. Rotate to **Pos 2** → **Capture Pos 2**.
4. (if 3-pos) Rotate to **Pos 3** → **Capture Pos 3**.
5. FCU computes thresholds between each pair of samples.
6. **Save slot**.

### 8.3 Assign modes

Under **Selector → Pos 1/2/3 Mode**, choose a firing mode per position. These fields apply regardless of input type (digital or Hall).

---

## 9. First use and web panel access

### First-boot

On first power-up (or after flashing a build that bumped the schema), NVS is re-initialized with defaults. Two long beeps (BOOT + READY) confirm first-boot; subsequent power-ups only play BOOT.

**Initial defaults:**

- 3 slots named `Slot 1`, `Slot 2`, `Slot 3`
- D8PA, 2-pos, Pos1=SEMI, Pos2=FULL
- Digital trigger (microswitch, active-LOW)
- Timings `DN=18 ms / DR=26 ms / DP=25 ms / DB=100 units (10 ms)`
- SSID = `BCGA_FCU_STR` or `BCGA_FCU_PRO`
- WiFi password = `12345678`

### Open the panel

Connect your phone/laptop to the AP and open any URL — the captive DNS redirects to the panel. Fixed address: `http://192.168.4.1`.

**Turn the AP on:**

| Variant | Gestures |
|---|---|
| **STR** | Hold the trigger for 5 s during the first 5 s after boot; OR 5 trigger pulls in SAFE within 3 s |
| **PRO** | Dedicated WiFi button; OR the same gestures above |

AP shuts off automatically after **10 min of web inactivity** (3 beeps).

---

## 10. Slots

3 independent slots. Each one holds **everything**: firing type (S8PA/D8PA), timings, selector, Hall calibrations, flags. Switch via the buttons at the top of the page.

The FCU remembers the last slot used and returns to it after reboot.

**Typical use:**
- Slot 1 = your main setup
- Slot 2 = aggressive tune (higher ROF, tighter DR)
- Slot 3 = backup / test

---

## 11. Useful flags

- **Invert trigger** — check if your microswitch is active-HIGH (rare).
- **Swap MOS** (D8PA only) — swaps SOL1↔SOL2 **in software**. Use if you soldered them backwards and don't want to desolder.
- **Silent mode** — mutes beeps only *during firing*. Mode-change beep still plays.

---

## 12. Limit rate of fire

### ROF limit (rounds/sec)

Global ceiling. If your timings allow 25 rps but you want 15 rps, set `15`. A delay is inserted automatically between shots.

- `0` = unlimited (ROF determined purely by the timings)
- Too low = FCU ignores your FULL pull until the limit allows the next shot

### Semi ROF (ms)

Cooldown **between SEMI pulls**. Prevents trigger spam (fast finger).

- `0` = disabled
- `150 ms` = caps at ~6 SEMI pulls/sec
- Does not affect FULL/BURST

---

## 13. Diagnostics and WiFi

### MOS test

- **Test MOS 1** — pulses MOSFET 1 for 2 s.
- **Test MOS 2** — pulses MOSFET 2 for 2 s (honors `Swap MOS`).

Use with a multimeter, LED, or solenoid to verify wiring.

> Refuses if the FCU is actively firing.

### Buzzer test

Plays each beep type. Useful to learn the sounds before a game. On STR the piezo is not populated by default; the code still runs but stays silent unless you add one to PIN_BUZZER.

### Change WiFi password

**WiFi** section → new password (min **8 characters**) → **Save**. Persists in NVS. Only resets on factory reset.

### Factory reset

Two ways:
1. Flash a build that bumps `STORAGE_INIT_VERSION` (NVS is wiped on next boot automatically).
2. If your build exposes **Advanced → Factory reset** on the panel.

---

## 14. Deep sleep, inactivity alarm and debug mode

### Inactivity alarm (NEW)

After **60 minutes without any user activity** (trigger pull, WiFi button press, selector change, or web UI interaction), the FCU enters an alarm sequence designed to grab your attention before sleeping:

- **6 alarm cycles**, each consisting of:
  - 5 minutes of short beeps every 30 seconds
  - Then 1 hour of deep sleep
  - Then wake and start the next cycle
- After all 6 cycles complete (~6 hours total), the FCU enters **permanent deep sleep**
- **Any activity resets the counter** and returns to normal operation

This protects against forgetting the FCU powered on, but **does not preserve the battery indefinitely** — see below.

### Deep sleep behavior

When the FCU enters deep sleep:
- ESP32-C3 draws **<10 µA**
- The voltage regulators on the PRO board (MP2315 buck, MT3608 boost, AMS1117 LDO) **continue drawing ~12-18 mA** as long as the battery is connected
- Total board draw in deep sleep: ~12-18 mA (regulators only)

A 1000 mAh battery will fully discharge in **2-3 days** if left connected, even if the ESP32 is sleeping.

> ⚠️ **The only way to truly preserve the battery between sessions is to physically disconnect it.**

### Wake-up

After deep sleep, the next trigger pull **wakes the MCU via full reboot** — the second pull is the one that actually fires.

### Debug mode (5 min)

For bench testing, edit `firmware/BCGA_FCU_{STR,PRO}/config.h` and uncomment:

```c
#define DEEP_SLEEP_DEBUG
```

Inactivity timeout drops from 60 min to 5 min. **Re-comment before shipping to production.**

### Battery lockout (PRO only)

The PRO variant monitors battery voltage and protects against deep discharge through **lockout mode** (not automatic cut-off — see below).

**Thresholds (per cell):**
- **Low warning**: 3.5 V/cell — single beep every 10 seconds
- **Critical**: 3.2 V/cell — single beep every 5 seconds
- **Cut (lockout)**: 3.0 V/cell — firing blocked, beep every 5 seconds

When lockout is triggered:
1. Firing is permanently disabled until reboot (battery reconnect)
2. Beep alert sounds every 5 seconds
3. After ~30 minutes of beeping (360 cycles), FCU enters permanent deep sleep
4. **Battery is not cut off** — you must physically disconnect to prevent further discharge

> ⚠️ **The PRO variant V2.1 does NOT have automatic battery cut-off.** Earlier versions (V2.0 and earlier) had a kill latch circuit that physically disconnected the battery — this was removed in V2.1 to simplify the circuit and eliminate a bootstrap reliability issue. The lockout mode + audible alarm is the new protection mechanism, but it relies on the user disconnecting the battery.

---

## 15. STR vs PRO differences

| Feature | STR | PRO |
|---|:---:|:---:|
| S8PA (1 solenoid) | ✅ | ✅ |
| D8PA (2 solenoids) | ✅ | ✅ |
| All modes (SAFE/SEMI/FULL/BURST2-4) | ✅ | ✅ |
| 3-pos Hall selector | ✅ | ✅ |
| Full Hall calibration | ✅ | ✅ |
| Web panel + AP gesture opening | ✅ | ✅ |
| 60 min deep sleep | ✅ | ✅ |
| Inactivity alarm (6 cycles → permanent sleep) | ✅ | ✅ |
| **Battery voltage read** | ❌ | ✅ |
| **Battery lockout** (firing block at critical V) | ❌ | ✅ |
| **Kill latch** (LiPo deep-discharge protection) | ❌ | ❌ (V2.1: lockout) |
| **Dedicated WiFi button** | ❌ | ✅ |
| **Onboard buzzer** | ❌ | ✅ |

---

## 16. BCGA FCU vs commercial FCUs

This section compares the BCGA FCU to the main commercial FCUs in the airsoft HPA market (PolarStar REV3, Wolverine BLINC, GATE TITAN II, Gorilla FCU). It is factual and includes both advantages and gaps.

### 16.1 Where the BCGA FCU wins

1. **Native WiFi vs Bluetooth.** Configure from any browser on any device — iOS, Android, PC, Linux, anything that opens a web page. No app install, no pairing, no vendor lock-in. TITAN II (BLE 5.2), BLINC and Gorilla all require proprietary apps.

2. **4 independent timings (DN/DR/DP/DB).** Each phase of the D8PA cycle has its own parameter. Feeding (DN), sealing (DR), FPS (DP) and post-shot debounce (DB) are tuned independently without trade-offs. Commercial FCUs top out at 3 user-facing timings (REV3 in dual-solenoid mode: dP/dN/dr) or a single dwell on single-solenoid setups. No commercial FCU exposes a dedicated post-shot debounce.

3. **Automatic Hall trigger EMI noise calibration.** The only FCU on the market with a routine that fires the solenoids dry and measures the EMI kick on the ADC, widening the Hall deadband automatically. Eliminates ghost fires without sacrificing trigger sensitivity.

4. **3 complete independent slots.** Each slot stores **everything** — engine type, all 4 timings, selector config, individual Hall calibrations, flags. Switching slots = full game-profile switch.

5. **Open-source, GPL v3.** All code is public. Audit, modify, compile and flash without depending on proprietary firmware or a vendor app. TITAN II, BLINC, REV3 and Gorilla are fully closed.

6. **Hall trigger with 2-point calibration + automatic hysteresis.** Captures the exact fire point and computes a hysteresis band from real measurements — not fixed values. No mechanical potentiometer.

7. **3-position Hall selector.** SAFE/SEMI/FULL via a wear-free Hall sensor. Each position freely configurable to any mode (including BURST 2/3/4).

8. **Drastically lower BOM cost.** The STR can be built from easily sourced THT parts for a fraction of any commercial Bluetooth FCU.

9. **Live theoretical ROF in the UI.** The web panel shows maximum achievable ROF as you move the sliders — no chrono needed for a first-pass estimate.

10. **Per-slot S8PA/D8PA switching in software.** Each of the 3 slots independently stores the engine type — flip a slot between S8PA and D8PA directly from the web UI, no hardware change. Commercial FCUs that cover both architectures (TITAN II with PULSAR S/D, Gorilla) do it through separate dedicated cable harnesses per engine, not per-slot software switching.

### 16.2 Honest limitations

Buyers need to know these before choosing the BCGA FCU:

1. **No binary trigger.** Not implemented. Available on Wolverine BLINC, GATE TITAN II and Gorilla FCU.
2. **No tournament lock with password.** Workaround: set Semi ROF high and ROF limit low before an event. Available on TITAN II (Expert) and Gorilla.
3. **No automatic battery cut-off.** The PRO variant enters lockout mode (firing disabled, continuous alarm) at critical battery voltage, but does not physically cut the battery — user must disconnect manually. The STR variant has no battery voltage read at all. Use with caution on 2S/3S packs without external protection.
4. **Battery drains while plugged in.** The voltage regulators draw ~12-18mA continuously. A 1000mAh pack discharges fully in 2-3 days if left connected. Disconnect between sessions.
5. **First pull after deep sleep wakes via reboot.** After 60 min of idle the FCU deep-sleeps. The next pull wakes the MCU through a full reboot — the **second** pull is the one that actually fires. Different from FCUs that sleep via MOSFET gate-hold.

### 16.3 Side-by-side comparison

| Dimension | BCGA FCU STR/PRO | PolarStar REV3 | Wolverine BLINC | GATE TITAN II | Gorilla FCU |
|---|---|---|---|---|---|
| MCU | ESP32-C3 | Proprietary | Proprietary | ARM + BLE 5.2 | Proprietary + BLE |
| License | **GPL v3 (open-source)** | Proprietary | Proprietary | Proprietary | Proprietary |
| Single-solenoid | ✅ (S8PA) | ✅ (FCF1) | ✅ | ✅ (PULSAR S) | ✅ |
| Dual-solenoid | ✅ (D8PA) | ✅ (FCFE) | ❌ (single only) | ✅ (PULSAR D) | ✅ |
| Independent timings | **4 (DN/DR/DP/DB)** | 3 (dual) / 1 (single) | 1 + autotune | Auto cycle-sync or manual | Separate SEMI/AUTO dwells |
| Interface | **Web UI over WiFi** | LCD + joystick | BLE app | BLE 5.2 app | BLE app |
| App required | **No** | No | ✅ required | ✅ required | ✅ required |
| Hall noise calibration | **✅ unique on the market** | ❌ | ❌ | ❌ | ❌ |
| Configuration slots | **3 complete** | 1 set | 1 profile | Per-engine profiles | 1 set |
| Binary trigger | ❌ | Hack (burst=01) | ✅ | ✅ | ✅ |
| Tournament lock | ❌ | — | ❌ | ✅ (Expert) | ✅ |
| Approximate cost | **~R$50–100 BOM** | ~US$80 FCU | ~US$160 | ~US$300–440 combo | ~US$200 |
| Deep sleep | ✅ 60 min + alarm | — | ✅ | ✅ | — |
| Battery cut-off | ❌ (PRO: lockout) | — | — | — | — |

### 16.4 Who the BCGA FCU is for

- **DIY HPA builders** who want full control over the firing cycle with 4 independent timings.
- **Field installers** without a specific Bluetooth app on their phone — any browser works.
- **Budget-conscious makers** building an S8PA/D8PA engine from scratch.
- **Open-source advocates** who won't ship a closed-firmware gun.
- **Anyone who wants 3 distinct game profiles** in a single FCU (skirmish, DMR, CQB).

The BCGA FCU is **not** the right choice if you need binary trigger or password-locked tournament mode out of the box — pick TITAN II, BLINC or Gorilla for those.

---

## License

GPL v3 — see [LICENSE](LICENSE).

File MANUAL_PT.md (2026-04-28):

# BCGA FCU — Manual de Uso (PT-BR)

Firmware open-source para ESP32-C3 SuperMini. Duas variantes: **STR** (Starter, perfboard) e **PRO** (produto comercial). A interface web e a lógica de disparo são quase idênticas — as diferenças estão no fim do documento.

Esse manual é prático: cada seção começa com **o que mexer para obter o quê**.

> 🇬🇧 English version: [MANUAL_EN.md](./MANUAL_EN.md)

---

## Índice

1. [Entendendo a FCU em 1 minuto](#1-entendendo-a-fcu-em-1-minuto)
2. [Início rápido — chegar no FPS alvo primeiro](#2-inicio-rapido--chegar-no-fps-alvo-primeiro)
3. [Os 4 timings — guia de tuning](#3-os-4-timings--guia-de-tuning)
4. [Fluxo recomendado de tuning](#4-fluxo-recomendado-de-tuning)
5. [Tipo de disparo: S8PA vs D8PA](#5-tipo-de-disparo-s8pa-vs-d8pa)
6. [Seletor — 2 ou 3 posições](#6-seletor--2-ou-3-posicoes)
7. [Gatilho Hall — calibração passo a passo](#7-gatilho-hall--calibracao-passo-a-passo)
8. [Seletor Hall — calibração passo a passo](#8-seletor-hall--calibracao-passo-a-passo)
9. [Primeiro uso e acesso ao painel Web](#9-primeiro-uso-e-acesso-ao-painel-web)
10. [Slots](#10-slots)
11. [Flags úteis (inverter gatilho, swap MOS, silent)](#11-flags-uteis)
12. [Limitar cadência (ROF limit e Semi ROF)](#12-limitar-cadencia)
13. [Diagnóstico e WiFi](#13-diagnostico-e-wifi)
14. [Deep sleep, alarme de inatividade e modo debug](#14-deep-sleep-alarme-de-inatividade-e-modo-debug)
15. [Diferenças STR vs PRO](#15-diferencas-str-vs-pro)
16. [BCGA FCU vs FCUs comerciais](#16-bcga-fcu-vs-fcus-comerciais)

---

## 1. Entendendo a FCU em 1 minuto

A FCU controla **1 ou 2 solenoides** que substituem o gatilho mecânico de um engine HPA. Em cada tiro, ela envia pulsos eletricamente calibrados para os solenoides, na ordem correta, com as esperas corretas entre eles. Tuning = ajustar esses pulsos para o teu sistema específico (pressão, bucking, BB, peso).

- **S8PA** (1 solenoide): PolarStar JACK / F1, Wolverine INFERNO, GATE PULSAR S, ou qualquer outro engine HPA de 1 solenoide. Só o poppet é controlado.
- **D8PA** (2 solenoides): PolarStar F2 / Fusion Engine, GATE PULSAR D, ou qualquer outro engine HPA de 2 solenoides. Nozzle + poppet controlados separadamente.

---

## 2. Início rápido — chegar no FPS alvo primeiro

Primeira vez na BCGA FCU? Antes de tudo, acerte o FPS alvo. O resto do tuning só faz sentido com o chrono onde você quer. Os 4 timings (DN/DR/DP/DB) estão explicados na seção 3 — nessa primeira passada você só mexe no **DP** (o slider do poppet dwell) e no regulador.

1. **Coloque o regulador em 100 psi.** Pressão inicial padrão para a maioria dos setups D8PA.
2. **Mantenha os timings default** (`DN=18 / DR=26 / DP=25 / DB=100`). Já vêm assim de fábrica.
3. **Atire no chrono.** O FPS (ou joule) está no alvo?
   - **Sim** → pule direto pra seção 4 e ajuste alimentação, vedação e precisão.
   - **Não, abaixo do alvo** → passo 4.
4. **Suba o DP até o máximo do slider** (80 ms). Chrono de novo.
   - **FPS subiu pro alvo** → abaixe o DP passo a passo até o FPS começar a cair, depois volte 1–2 ms. Esse é o seu DP mínimo eficiente. Vá pra seção 4.
   - **FPS ainda baixo** → passo 5.
5. **Aumente o regulador pra 110 psi.** Chrono de novo.
   - **No alvo** → abaixe o DP até achar o mínimo que segura o FPS alvo. Vá pra seção 4.
   - **Ainda baixo** → suba pra **120 psi** e chrono de novo.
6. Com FPS alvo estável, **vá pra seção 4** e ajuste DN (alimentação), DR (vedação) e DB (precisão) nessa ordem.

> **Princípio:** FPS é dado principalmente por **pressão × DP**. Os outros 3 timings moldam *como* o ciclo se comporta (alimentação, vedação, precisão, ROF) — não somam FPS. Acerte o FPS primeiro com DP/pressão, ajuste o resto depois.

---

## 3. Os 4 timings — guia de tuning

A FCU expõe **4 timings independentes** que mapeiam diretamente para cada fase física do ciclo de disparo: **DN**, **DR**, **DP**, **DB**. A página mostra o ROF teórico em tempo real enquanto você mexe nos sliders.

> **Nota sobre unidades:** DN, DR e DP estão em **milissegundos** (faixa 2–80 ms). O **DB** (Trigger Debounce) usa **units** — 1 unit = 0,1 ms, faixa 20–800 units (= 2–80 ms). Isso alinha o DB à resolução interna de 0,1 ms do firmware.

### DN — Nozzle Dwell (só D8PA)

Duração do pulso do **nozzle (SOL2)**. É quanto tempo o nozzle fica aberto para a BB cair na câmara.

| Se DN aumenta | Se DN diminui |
|---|---|
| ✅ alimentação mais fácil (BBs pesadas, pressão baixa, cold shot) | ✅ economiza ar, previne dupla alimentação |
| ❌ **risco de dupla alimentação** (2 BBs caem) | ❌ tiro vazio / alimentação inconsistente se o spring de retorno for lento |
| ❌ mais desgaste no nozzle | ❌ pode não selar direito antes do DP |

**Regra prática:** diminua DN até começar a dar tiro vazio, depois adicione 1–2 ms de margem.

### DR — Return / Rest

- **Em D8PA**: espera entre o pulso do nozzle e o pulso do poppet. É o tempo para o nozzle voltar e o **bucking selar na BB**.
- **Em S8PA**: descanso entre tiros (inter-shot rest).

| Se DR aumenta | Se DR diminui |
|---|---|
| ✅ vedação consistente → **FPS estável** | ✅ **ROF mais alto** |
| ✅ menos dispersão tiro-a-tiro | ❌ poppet dispara antes de selar → tiro fraco / FPS baixo e variável |
| ❌ ROF mais baixo | ❌ BBs caindo na frente do nozzle aberto = dupla / pick-up ruim |

**Regra prática:** suba DR até o chrono parar de oscilar em SEMI rápido.

### DP — Poppet Dwell (o tiro)

Duração do pulso do **poppet (SOL1)**. É quanto tempo o ar pode fluir pelo nozzle empurrando a BB.

| Se DP aumenta | Se DP diminui |
|---|---|
| ✅ **FPS mais alto** (mais ar atrás da BB) | ✅ economiza ar (mais tiros por garrafa/mag) |
| ❌ desperdício de ar após a BB sair | ✅ ROF mais alto (valve fecha rápido) |
| ❌ pode atrasar recycle do poppet | ❌ **FPS abaixo do alvo**, tiro sem potência |

**Regra prática:** com chrono, ajuste DP até chegar ao FPS alvo. Mais que isso é só desperdício.

### DB — Trigger Debounce (só D8PA)

Espera após o poppet fechar, antes do gatilho poder armar o próximo ciclo. Fisicamente é o tempo para a **BB sair do cano** e o bucking se recuperar.

**Unidade:** 1 unit = 0,1 ms. **Faixa:** 20–800 units (2–80 ms). **Default:** 100 units (10 ms).

| Units | Equivalente em ms |
|---:|---:|
| 20  | 2,0  |
| 50  | 5,0  |
| 100 | 10,0 |
| 200 | 20,0 |
| 800 | 80,0 |

| Se DB aumenta | Se DB diminui |
|---|---|
| ✅ **melhor precisão** (BB já saiu quando o próximo nozzle abre) | ✅ **ROF mais alto** |
| ✅ bucking recupera forma sem perturbação | ❌ BB ainda dentro do cano quando o próximo nozzle pulsa → **flyers / FPS inconsistente** |
| ❌ ROF mais baixo | ❌ vida útil reduzida do bucking |

**Regra prática:** atire em full-auto num alvo a 20 m. Se aparecerem flyers, aumente DB 20 units (2 ms) por vez.

### Defaults (D8PA genérico, 110 psi, BB 0.28)

```
DN = 18 ms    DR = 26 ms    DP = 25 ms    DB = 100 units (10 ms)
```

Ponto de partida seguro. Ajuste a partir daí.

---

## 4. Fluxo recomendado de tuning

Siga nesta ordem — cada passo depende do anterior estar estável. Assume que você já atingiu o FPS alvo pela seção 2.

1. **Alimentação (DN)** — dispare SEMI lento. Diminua DN até pegar tiro vazio. Volte 2 ms.
2. **Vedação (DR)** — dispare SEMI rápido. Se o chrono oscilar, aumente DR 2 ms.
3. **FPS (DP)** — com chrono, ajuste DP até atingir o alvo. Não suba mais que o necessário.
4. **Precisão (DB, só D8PA)** — full-auto em alvo. Se flyers, aumente DB em 20 units.
5. **Cadência (ROF limit)** — opcional. Limita o ROF máximo independentemente dos timings.
6. **Anti-spam (Semi ROF)** — opcional. Define tempo mínimo entre puxadas em SEMI.

> ⚠️ Cheque sempre com chrono. FPS drifta com temperatura da garrafa / nível de ar.

---

## 5. Tipo de disparo: S8PA vs D8PA

Escolhido por slot, na primeira seção do painel.

- **S8PA** — só o poppet é pulsado. Ciclo: `DP → DR → repete`. Use com PolarStar JACK / F1, Wolverine INFERNO, GATE PULSAR S, ou qualquer engine HPA de 1 solenoide. Os campos DN, DB, swap MOS e o botão de teste do SOL 2 somem da interface.
- **D8PA** — nozzle + poppet separados. Ciclo: `DN → DR → DP → DB → repete`. Use com PolarStar F2 / Fusion Engine, GATE PULSAR D, ou qualquer sistema com 2 solenoides.

---

## 6. Seletor — 2 ou 3 posições

Ativar "3 posições" **exige seletor Hall** (o microswitch só diferencia 2 estados). Ao ligar, a interface revela Pos 3.

Cada posição é atribuída a um modo **independente**:

| Modo | Comportamento |
|---|---|
| **SAFE** | Puxar o gatilho não faz nada. Beeps de modo continuam. |
| **SEMI** | Um tiro por puxada. Respeita Semi ROF se configurado. |
| **FULL** | Dispara enquanto o gatilho estiver pressionado. |
| **BURST 2 / 3 / 4** | Dispara 2/3/4 tiros por puxada, mesmo soltando o gatilho. |

Exemplos comuns:
- **2 posições**: Pos 1 = SAFE, Pos 2 = SEMI *(ou Pos 1 = SEMI, Pos 2 = FULL)*
- **3 posições**: Pos 1 = SAFE, Pos 2 = SEMI, Pos 3 = FULL

---

## 7. Gatilho Hall — calibração passo a passo

Use Hall se quiser um gatilho **sem desgaste mecânico** e com **ponto de disparo ajustável**.

**Hardware esperado:** sensor Hall linear (DRV5055 ou similar) alimentado em 3.3 V, saída ligada em **PIN_TRIG** (GPIO 0 em ambas variantes). Ímã na alavanca do gatilho.

### 7.1 Seleção do modo

Seção **Entrada** → "Tipo gatilho" → **Hall** → **Salvar**.

### 7.2 Calibração rápida (single-point)

Para a maioria dos casos — 30 segundos.

1. Na seção **Sensibilidade**, puxe o gatilho **até o ponto exato onde quer que dispare** e segure.
2. Clique **Capturar ponto**.
3. A FCU lê o ADC e cria automaticamente uma banda de histerese simétrica em torno desse valor.
4. Salve o slot.

Se disparar antes de chegar no ponto → capture num ponto um pouco mais puxado.
Se não disparar mesmo puxando até o fim → capture num ponto menos puxado.

### 7.3 Calibração completa (para máxima precisão)

Na seção **Calibração do gatilho**:

1. **Calibração de ruído**
   - A FCU dispara **um ciclo completo sem BB** medindo o ADC durante o pulso dos solenoides.
   - Calcula o ruído EMI e **alarga automaticamente a banda morta** do gatilho.
   - Previne disparo-fantasma causado pelo próprio chute dos MOSFETs.
   - ⚠️ **Rode com a gearbox montada e garrafa conectada** — o ruído depende do setup físico.

2. **Captura Solto**
   - Gatilho totalmente solto → **Capturar Solto**.

3. **Captura Pressionado**
   - Gatilho totalmente puxado → **Capturar Pressionado**.

4. A FCU calcula o threshold central e uma banda de histerese baseada nos dois pontos + ruído medido.

5. **Salvar slot**.

### Tuning do gatilho Hall

| Sintoma | Causa provável | Ajuste |
|---|---|---|
| Dispara sozinho (fantasma) | Ruído EMI do solenoide maior que a banda morta | Re-rode a calibração de ruído |
| Dispara antes do ponto | Threshold baixo demais | Re-capture num ponto mais próximo do final |
| Não dispara até o fim | Threshold alto demais ou sensor mal-posicionado | Re-capture, ou aproxime mais o ímã |
| Intermitente no limiar | Banda de histerese estreita | Use calibração completa em vez de single-point |

---

## 8. Seletor Hall — calibração passo a passo

Hall no seletor permite **3 posições físicas** (SAFE/SEMI/FULL clássico) ou simplesmente uma leitura mais confiável de 2 posições.

**Hardware esperado:** sensor Hall linear no corpo da gearbox, com ímã na placa de seleção. Saída em **PIN_SEL** (GPIO 1).

### 8.1 Seleção do modo

Seção **Entrada** → "Tipo seletor" → **Hall** → marque "3 posições" se aplicável → **Salvar**.

### 8.2 Calibração

Seção **Calibração do seletor**:

1. **Calibração de ruído** (opcional mas recomendada) — mesmo princípio do gatilho.
2. Rode o seletor para **Pos 1** → **Capturar Pos 1**.
3. Rode para **Pos 2** → **Capturar Pos 2**.
4. (se 3-pos) Rode para **Pos 3** → **Capturar Pos 3**.
5. A FCU calcula os thresholds entre cada par de amostras.
6. **Salvar slot**.

### 8.3 Atribuir modos

Em **Seletor → Pos 1/2/3 Modo**, escolha um modo de disparo para cada posição. Estes campos funcionam independente do tipo (digital ou Hall).

---

## 9. Primeiro uso e acesso ao painel Web

### First-boot

Ao ligar pela primeira vez (ou após flashar uma build nova que mudou schema), a NVS é reinicializada com os defaults. Dois beeps longos (BOOT + READY) confirmam o first-boot; depois só toca BOOT em cada power-up normal.

**Defaults iniciais:**

- 3 slots nomeados `Slot 1`, `Slot 2`, `Slot 3`
- D8PA, 2-pos, Pos1=SEMI, Pos2=FULL
- Gatilho digital (microswitch, active-LOW)
- Timings `DN=18 ms / DR=26 ms / DP=25 ms / DB=100 units (10 ms)`
- SSID = `BCGA_FCU_STR` ou `BCGA_FCU_PRO`
- Senha WiFi = `12345678`

### Abrir o painel

Conecte o celular/notebook ao AP e abra qualquer URL — o DNS captive redireciona para o painel. Endereço fixo: `http://192.168.4.1`.

**Ligar o AP:**

| Variante | Gestos |
|---|---|
| **STR** | Segurar o gatilho por 5 s durante os primeiros 5 s pós-boot; OU 5 puxadas em SAFE dentro de 3 s |
| **PRO** | Botão WiFi dedicado; OU os mesmos gestos acima |

AP desliga sozinho após **10 min sem atividade web** (3 beeps).

---

## 10. Slots

3 slots independentes. Cada um guarda **tudo**: tipo (S8PA/D8PA), timings, seletor, calibrações Hall, flags. Troque pelo botão no topo da página.

A FCU lembra qual era o último slot usado e volta para ele após reboot.

**Uso típico:**
- Slot 1 = seu setup principal
- Slot 2 = ajuste agressivo (mais ROF, menos DR)
- Slot 3 = backup / teste

---

## 11. Flags úteis

- **Inverter gatilho** — marque se o seu microswitch é active-HIGH (raro).
- **Swap MOS** (só D8PA) — inverte SOL1↔SOL2 **por software**. Use se você soldou errado e não quer dessoldar.
- **Silent mode** — silencia apenas os beeps *durante* o tiro. Beep de troca de modo continua.

---

## 12. Limitar cadência

### ROF limit (rounds/sec)

Teto geral. Se seus timings permitem 25 rps mas você quer 15 rps, ponha `15`. Um delay é inserido automaticamente entre tiros.

- `0` = sem limite (ROF determinado só pelos timings)
- Valor baixo demais = a FCU ignora a sua puxada em FULL até o limit permitir o próximo tiro

### Semi ROF (ms)

Cooldown **entre puxadas** em modo SEMI. Previne trigger-spam (dedo rápido).

- `0` = desabilitado
- `150 ms` = no máximo ~6 puxadas/seg em SEMI
- Não afeta FULL/BURST

---

## 13. Diagnóstico e WiFi

### Teste MOS

- **Test MOS 1** — pulsa o MOSFET 1 por 2 s.
- **Test MOS 2** — pulsa o MOSFET 2 por 2 s (respeita `Swap MOS`).

Use com multímetro, LED, ou solenoide para verificar fiação.

> Recusa acontecer se a FCU estiver disparando.

### Buzzer test

Toca cada tipo de beep. Útil para identificar sons antes de sair pra jogar. No STR o piezo não vem populado de fábrica; o código continua rodando mas fica mudo a menos que você adicione um piezo no PIN_BUZZER.

### Trocar senha WiFi

Seção **WiFi** → nova senha (mínimo **8 caracteres**) → **Salvar**. Persiste em NVS. Só volta ao default num factory reset.

### Factory reset

Duas formas:
1. Flashar uma build que incrementa `STORAGE_INIT_VERSION` (NVS é limpa no próximo boot automaticamente).
2. Se a build expor **Avançado → Reset de fábrica** no painel.

---

## 14. Deep sleep, alarme de inatividade e modo debug

### Alarme de inatividade (NOVO)

Após **60 minutos sem qualquer atividade do usuário** (puxada de gatilho, botão WiFi, mudança de seletor ou interação no painel web), a FCU entra numa sequência de alarme desenhada para chamar sua atenção antes de dormir:

- **6 ciclos de alarme**, cada um composto por:
  - 5 minutos de beeps curtos a cada 30 segundos
  - Depois 1 hora de deep sleep
  - Depois acorda e inicia o próximo ciclo
- Ao completar os 6 ciclos (~6 horas no total), a FCU entra em **deep sleep permanente**
- **Qualquer atividade reseta o contador** e volta à operação normal

Isso protege contra esquecer a FCU ligada, mas **não preserva a bateria indefinidamente** — veja abaixo.

### Comportamento do deep sleep

Quando a FCU entra em deep sleep:
- O ESP32-C3 consome **<10 µA**
- Os reguladores de tensão da placa PRO (MP2315 buck, MT3608 boost, AMS1117 LDO) **continuam consumindo ~12-18 mA** enquanto a bateria estiver conectada
- Consumo total da placa em deep sleep: ~12-18 mA (só os reguladores)

Uma bateria 1000 mAh descarrega totalmente em **2-3 dias** se ficar plugada, mesmo com o ESP32 dormindo.

> ⚠️ **A única forma de realmente preservar a bateria entre sessões é desconectá-la fisicamente.**

### Despertar (wake-up)

Após deep sleep, a próxima puxada de gatilho **acorda o MCU via reboot completo** — a segunda puxada é a que dispara de fato.

### Modo debug (5 min)

Para bancada, edite `firmware/BCGA_FCU_{STR,PRO}/config.h` e descomente:

```c
#define DEEP_SLEEP_DEBUG
```

O timeout de inatividade cai de 60 min para 5 min. **Re-comente antes de entregar para produção.**

### Lockout de bateria (só PRO)

A variante PRO monitora a tensão da bateria e protege contra descarga profunda via **modo lockout** (não corte automático — veja abaixo).

**Thresholds (por célula):**
- **Aviso de baixa**: 3,5 V/célula — beep único a cada 10 segundos
- **Crítica**: 3,2 V/célula — beep único a cada 5 segundos
- **Cut (lockout)**: 3,0 V/célula — firing bloqueado, beep a cada 5 segundos

Quando o lockout é acionado:
1. Firing fica permanentemente desabilitado até reboot (reconexão da bateria)
2. Beep de alerta toca a cada 5 segundos
3. Após ~30 minutos de beeping (360 ciclos), a FCU entra em deep sleep permanente
4. **A bateria não é cortada** — você precisa desconectar fisicamente para evitar descarga adicional

> ⚠️ **A variante PRO V2.1 NÃO tem corte automático de bateria.** Versões anteriores (V2.0 e antes) tinham um circuito de kill latch que desconectava fisicamente a bateria — isso foi removido na V2.1 para simplificar o circuito e eliminar um problema de confiabilidade no bootstrap. O modo lockout + alarme sonoro é o novo mecanismo de proteção, mas depende do usuário desconectar a bateria.

---

## 15. Diferenças STR vs PRO

| Feature | STR | PRO |
|---|:---:|:---:|
| S8PA (1 solenoide) | ✅ | ✅ |
| D8PA (2 solenoides) | ✅ | ✅ |
| Todos os modos (SAFE/SEMI/FULL/BURST2-4) | ✅ | ✅ |
| Seletor Hall 3-pos | ✅ | ✅ |
| Calibração Hall completa | ✅ | ✅ |
| Painel web + gesto de abertura do AP | ✅ | ✅ |
| Deep sleep 60 min | ✅ | ✅ |
| Alarme de inatividade (6 ciclos → sleep permanente) | ✅ | ✅ |
| **Leitura de bateria** | ❌ | ✅ |
| **Modo lockout** (bloqueio de firing em tensão crítica) | ❌ | ✅ |
| **Kill latch** (protege LiPo de descarga profunda) | ❌ | ❌ (V2.1: lockout) |
| **Botão WiFi dedicado** | ❌ | ✅ |
| **Buzzer onboard** | ❌ | ✅ |

---

## 16. BCGA FCU vs FCUs comerciais

Esta seção compara a BCGA FCU com as principais FCUs comerciais do mercado airsoft HPA (PolarStar REV3, Wolverine BLINC, GATE TITAN II, Gorilla FCU). É uma avaliação factual — inclui vantagens e lacunas honestas.

### 16.1 Onde a BCGA FCU ganha

1. **WiFi nativo vs Bluetooth.** Configure pelo browser de qualquer dispositivo — iOS, Android, PC, Linux, qualquer coisa que abra uma página web. Sem instalar app, sem pareamento, sem vendor lock-in. TITAN II (BLE 5.2), BLINC e Gorilla exigem apps proprietários específicos.

2. **4 timings independentes (DN/DR/DP/DB).** Cada fase do ciclo D8PA tem seu próprio parâmetro. Alimentação (DN), vedação (DR), FPS (DP) e debounce pós-tiro (DB) são ajustados separadamente sem trade-offs. FCUs comerciais chegam no máximo a 3 timings expostos ao usuário (REV3 em modo dual-solenoid: dP/dN/dr) ou dwell único em single-solenoid. Nenhuma FCU comercial expõe parâmetro dedicado para debounce pós-tiro.

3. **Calibração automática de ruído EMI no gatilho Hall.** Única FCU do mercado com rotina que dispara os solenoides a seco e mede o chute EMI no ADC, alargando automaticamente o deadband do Hall. Elimina ghost fires sem sacrificar sensibilidade.

4. **3 slots completos e independentes.** Cada slot armazena **tudo** — tipo de engine, os 4 timings, configuração de selector, calibrações Hall individuais, flags. Trocar slot = trocar perfil de jogo completo.

5. **Open-source, GPL v3.** Código totalmente aberto. Auditar, modificar, compilar e flashar sem depender de firmware proprietário ou app do fabricante. TITAN II, BLINC, REV3 e Gorilla são fechados.

6. **Gatilho Hall com calibração de 2 pontos + histerese automática.** Captura o ponto exato de disparo e calcula banda de histerese a partir de medições reais — não valores fixos. Sem potenciômetro mecânico.

7. **Seletor Hall de 3 posições.** SAFE/SEMI/FULL via sensor Hall sem desgaste mecânico. Cada posição livre para qualquer modo (inclusive BURST 2/3/4).

8. **BOM drasticamente mais barato.** O STR pode ser construído com componentes THT fáceis de achar por uma fração do custo de qualquer FCU Bluetooth comercial.

9. **ROF teórico em tempo real na UI.** O painel web mostra o ROF máximo alcançável enquanto você mexe nos sliders — sem cronógrafo para uma estimativa inicial.

10. **Troca S8PA/D8PA por slot via software.** Cada um dos 3 slots armazena independentemente o tipo de engine — alterne o slot entre S8PA e D8PA direto pelo painel web, sem tocar em hardware. FCUs comerciais que cobrem as duas arquiteturas (TITAN II com PULSAR S/D, Gorilla) fazem isso via cabos dedicados distintos por engine, não via chaveamento por slot no software.

### 16.2 Limitações honestas

Quem está comprando precisa saber disto antes de escolher a BCGA FCU:

1. **Sem binary trigger.** Não implementado. Presente no Wolverine BLINC, GATE TITAN II e Gorilla FCU.
2. **Sem tournament lock com senha.** Contorno: configurar Semi ROF alto + ROF limit baixo antes do evento. Presente no TITAN II (Expert) e Gorilla.
3. **Sem corte automático de bateria.** A variante PRO entra em modo lockout (firing desabilitado, alarme contínuo) na tensão crítica, mas não corta fisicamente a bateria — o usuário precisa desconectar manualmente. A variante STR não tem leitura de bateria. Use com cuidado em packs 2S/3S sem proteção externa.
4. **Bateria drena enquanto está plugada.** Os reguladores de tensão consomem ~12-18mA continuamente. Um pack 1000mAh descarrega totalmente em 2-3 dias se ficar conectado. Desconecte entre sessões.
5. **Primeira puxada após deep sleep acorda via reboot.** Após 60 min de inatividade, a FCU entra em deep-sleep. A próxima puxada acorda o MCU por reboot completo — a **segunda** puxada é a que dispara. Diferente de FCUs que dormem por gate-hold do MOSFET.

### 16.3 Comparativo lado-a-lado

| Dimensão | BCGA FCU STR/PRO | PolarStar REV3 | Wolverine BLINC | GATE TITAN II | Gorilla FCU |
|---|---|---|---|---|---|
| MCU | ESP32-C3 | Proprietário | Proprietário | ARM + BLE 5.2 | Proprietário + BLE |
| Licença | **GPL v3 (open-source)** | Proprietária | Proprietária | Proprietária | Proprietária |
| Single-solenoid | ✅ (S8PA) | ✅ (FCF1) | ✅ | ✅ (PULSAR S) | ✅ |
| Dual-solenoid | ✅ (D8PA) | ✅ (FCFE) | ❌ (só single) | ✅ (PULSAR D) | ✅ |
| Timings independentes | **4 (DN/DR/DP/DB)** | 3 (dual) / 1 (single) | 1 + autotune | Auto cycle-sync ou manual | Dwells SEMI/AUTO separados |
| Interface | **Web UI via WiFi** | LCD + joystick | App BLE | App BLE 5.2 | App BLE |
| App necessário | **Não** | Não | ✅ obrigatório | ✅ obrigatório | ✅ obrigatório |
| Hall noise calibration | **✅ única no mercado** | ❌ | ❌ | ❌ | ❌ |
| Slots de configuração | **3 completos** | 1 set | 1 perfil | Perfis por engine | 1 set |
| Binary trigger | ❌ | Hack (burst=01) | ✅ | ✅ | ✅ |
| Tournament lock | ❌ | — | ❌ | ✅ (Expert) | ✅ |
| Custo aproximado | **~R$50–100 BOM** | ~US$80 FCU | ~US$160 | ~US$300–440 combo | ~US$200 |
| Deep sleep | ✅ 60 min + alarme | — | ✅ | ✅ | — |
| Corte de bateria | ❌ (PRO: lockout) | — | — | — | — |

### 16.4 Para quem é a BCGA FCU

- **Builders DIY HPA** que querem controle total sobre o ciclo de disparo com 4 timings independentes.
- **Instaladores de campo** sem um app Bluetooth específico no celular — qualquer browser serve.
- **Makers com orçamento apertado** construindo um engine S8PA/D8PA do zero.
- **Defensores de open-source** que não aceitam rifle com firmware fechado.
- **Quem quer 3 perfis distintos de jogo** numa única FCU (skirmish, DMR, CQB).

A BCGA FCU **não** é a escolha certa se você precisa de binary trigger ou tournament lock com senha de fábrica — para isso pegue TITAN II, BLINC ou Gorilla.

---

## Licença

GPL v3 — ver [LICENSE](LICENSE).

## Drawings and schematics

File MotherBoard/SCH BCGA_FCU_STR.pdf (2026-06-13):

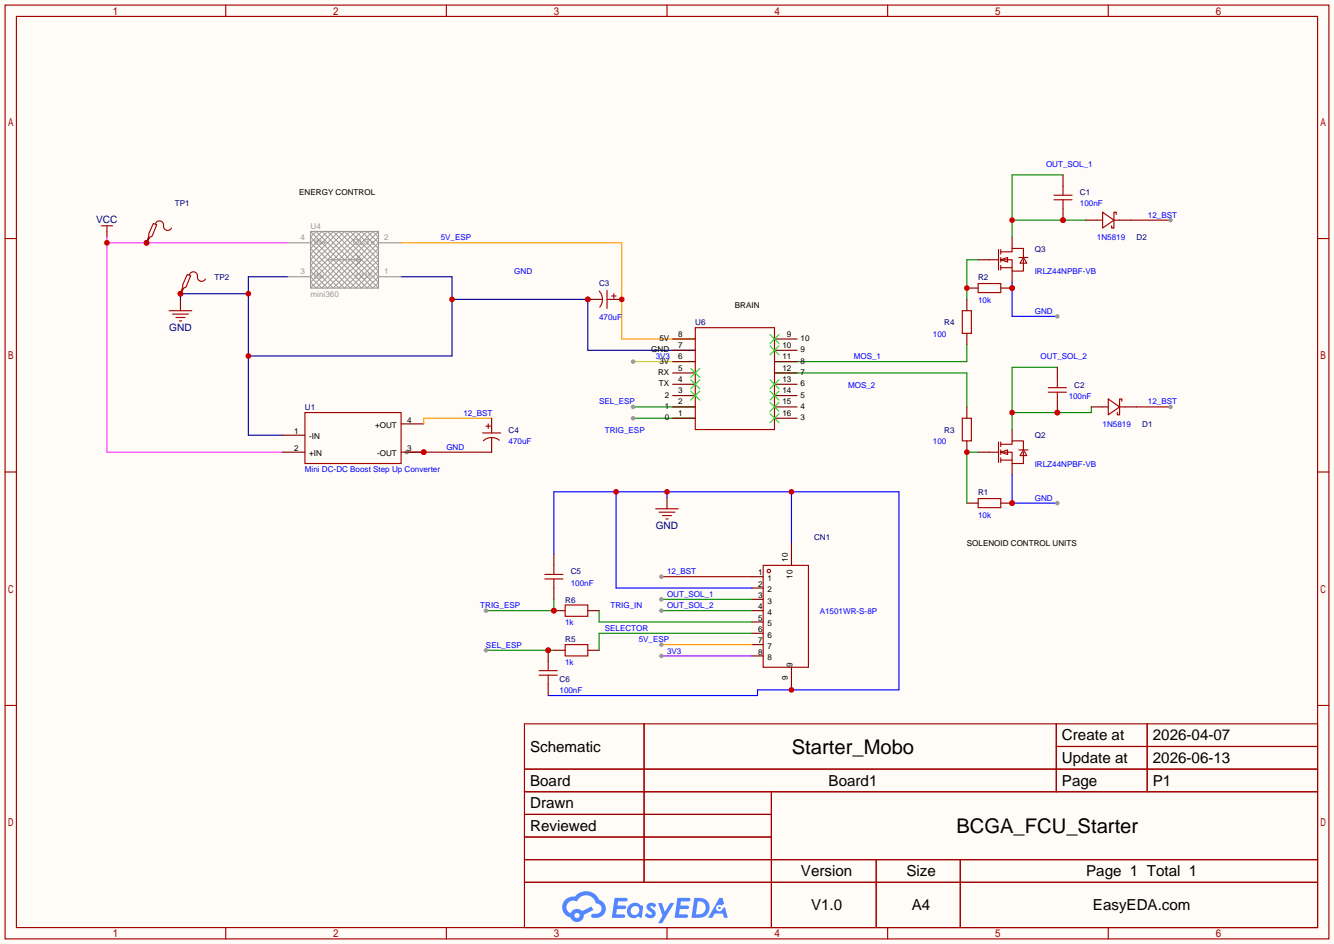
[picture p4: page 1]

Mini DC-DC Boost Step Up Converter

Schematic | Starter_Mobo | Create at | 2026-04-07

Update at | 2026-06-13

Board | Board1 | Page | P1
Drawn | | BCGA_FCU_Starter
Reviewed

Version | Size | Page 1 Total 1
V1.0 | A4 | EasyEDA.com

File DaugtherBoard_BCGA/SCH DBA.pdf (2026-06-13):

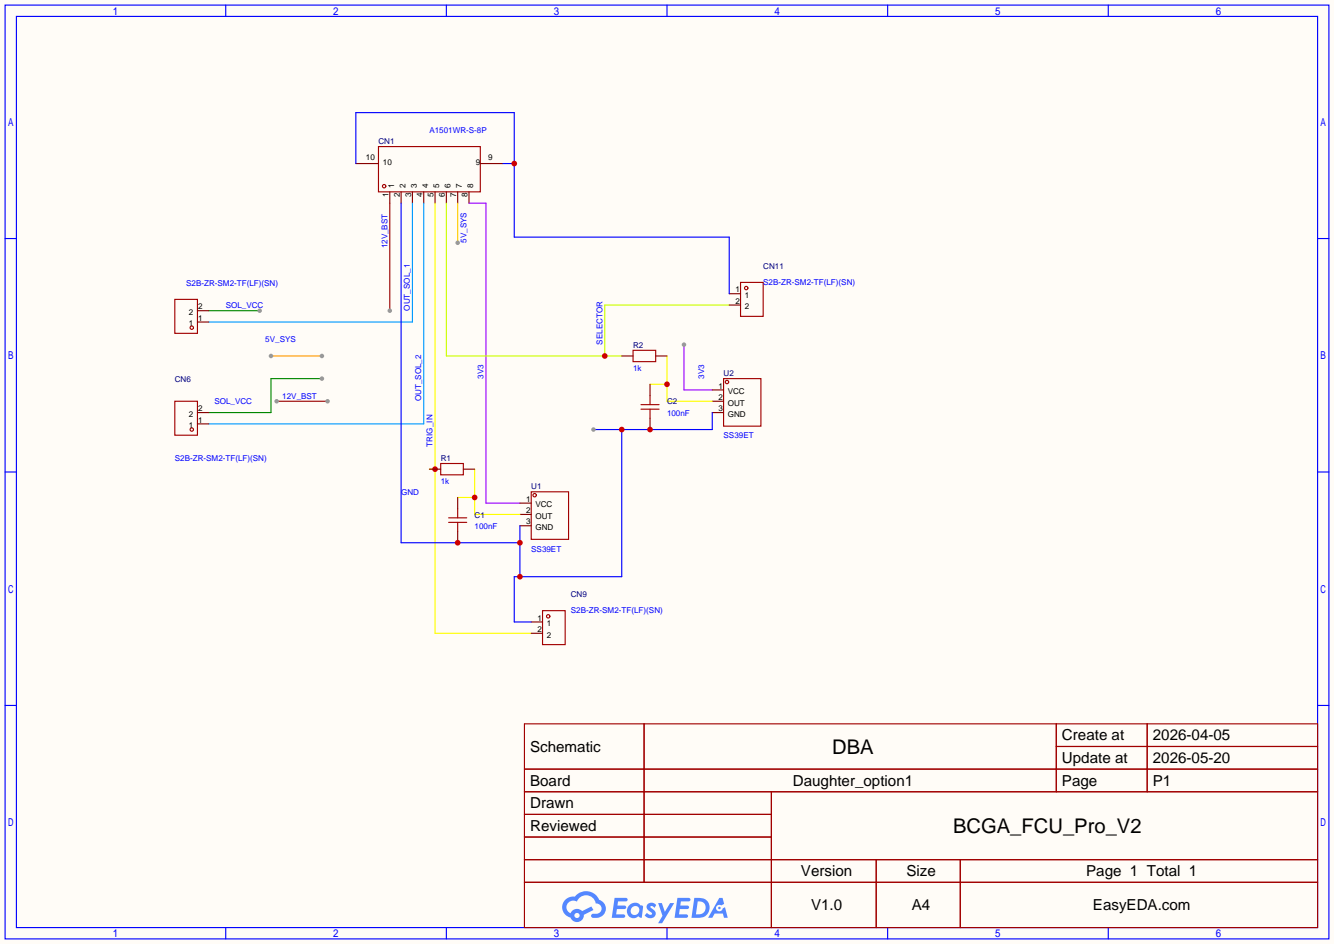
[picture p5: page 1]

Schematic | DBA | Create at | 2026-04-05

Update at | 2026-05-20

Board | Daughter_option1 | Page | P1
Drawn | | BCGA_FCU_Pro_V2
Reviewed

Version | Size | Page 1 Total 1
V1.0 | A4 | EasyEDA.com

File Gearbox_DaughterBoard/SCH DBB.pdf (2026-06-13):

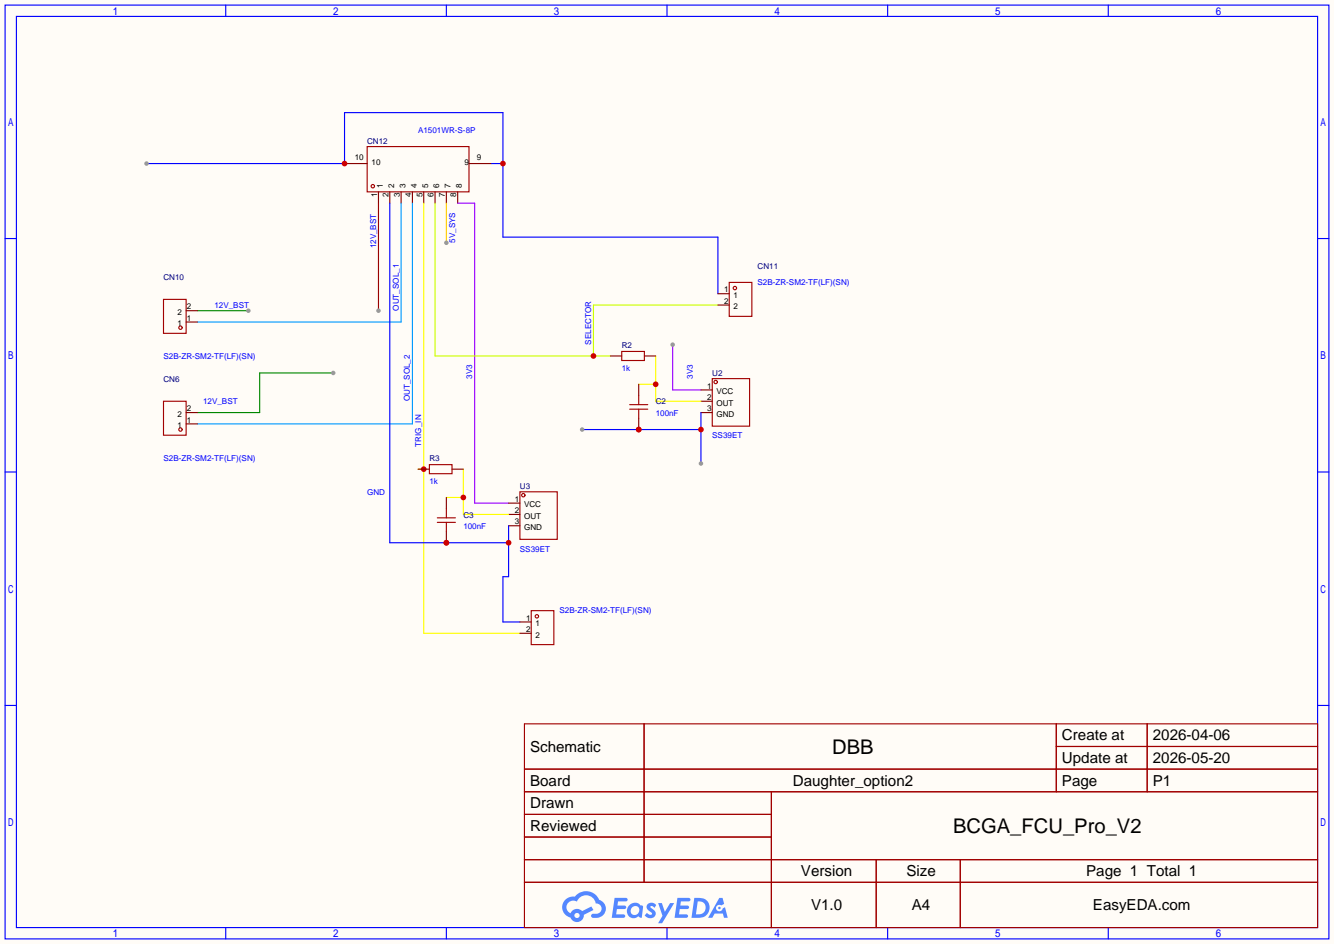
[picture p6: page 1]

Schematic | DBB | Create at | 2026-04-06

Update at | 2026-05-20

Board | Daughter_option2 | Page | P1
Drawn | | BCGA_FCU_Pro_V2
Reviewed

Version | Size | Page 1 Total 1
V1.0 | A4 | EasyEDA.com

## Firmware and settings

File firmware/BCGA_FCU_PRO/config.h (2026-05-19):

// BCGA FCU PRO — config.h
// Pin map, hardware constants, defaults.
// Target: ESP32-C3 SuperMini, BCGA FCU PRO board (battery sense, WiFi button,
// dual MOSFET). V2.1 dropped the kill-latch circuit; battery protection now
// uses the firmware lockout mode (firing block + audible alarm).

#pragma once

#include <Arduino.h>

// ============================================================================
// FIRMWARE METADATA
// ============================================================================
#define FW_NAME         "BCGA FCU PRO"
#define FW_VERSION      "2.1.1"
#define FW_VARIANT      "Pro"
#define FW_VARIANT_FULL "BCGA_FCU_PRO"

// ============================================================================
// PIN MAP — ESP32-C3 SuperMini
// ============================================================================
// Inputs
#define PIN_TRIG     0   // Trigger (Switch digital OR Hall analog), ADC1_CH0
#define PIN_SEL      1   // Selector (Switch digital OR Hall analog), ADC1_CH1
#define PIN_WIFI_BTN 3   // WiFi enable momentary button (active LOW, INPUT_PULLUP)
#define PIN_VBAT     4   // Battery voltage divider (ADC1_CH4)

// Outputs
#define PIN_MOS_1    8   // MOSFET 1 — SOL1 / Poppet (also onboard LED, inverted)
#define PIN_MOS_2    7   // MOSFET 2 — SOL2 / Nozzle
#define PIN_BUZZER  10   // 3V3 piezo buzzer (MLT-5020)

// Integrated 0.42" OLED (on the ESP32-C3 SuperMini module itself)
// SSD1306, 72×40 visible px, I²C addr 0x3C, ~30-col offset to glass.
#define PIN_OLED_SDA 5
#define PIN_OLED_SCL 6

// Reserved (do not use)
// GPIO 9     — boot strap / BOOT button (avoid)
// GPIO 18,19 — USB D+/D- (avoid)
// GPIO 20    — UART0 RX (logging)
// GPIO 21    — free on V2.1 (was PIN_LATCH on V2.0; latch circuit removed)

// ============================================================================
// FIRING TIMING
// ============================================================================
// DN/DR/DP are in milliseconds, clamped FIRE_MIN_MS..FIRE_MAX_MS.
// DB (Trigger Debounce) is in units of 0.1 ms, clamped DB_MIN_UNITS..DB_MAX_UNITS.
// Cycle order:
//   D8PA: pulse SOL2 (DN) → wait DR → pulse SOL1 (DP) → wait DB → repeat
//   S8PA: pulse SOL1 (DP) → wait DR → repeat
#define FIRE_MIN_MS         2   // 2 ms minimum pulse for DN/DR/DP
#define FIRE_MAX_MS        80   // 80 ms maximum pulse for DN/DR/DP
#define DB_MIN_UNITS        5   //  0.5 ms minimum DB (1 unit = 0.1 ms)
#define DB_MAX_UNITS      150   // 15.0 ms maximum DB

// Defaults if NVS empty — values validated on the bench.
#define DEFAULT_DN_MS      24   // Nozzle Dwell — SOL2 pulse (D8PA only)
#define DEFAULT_DR_MS      24   // D8PA: seal wait. S8PA: inter-shot rest.
#define DEFAULT_DP_MS      24   // Shot Poppet — SOL1 pulse
#define DEFAULT_DB_UNITS    5   // Trigger Debounce — D8PA only (5 × 0.1 ms = 0.5 ms)
#define DEFAULT_ROF_LIMIT   0   // 0 = unlimited
#define DEFAULT_SOLENOIDS   2   // 1 = S8PA, 2 = D8PA
#define DEFAULT_SEMI_ROF_MS 0   // 0 = disabled; ms to ignore trigger after semi shot

// Anti-stiction. Idle ≥ IS seconds → next shot's SOL1 pulse is multiplied by
// (1 + IP) so each IP step adds one full DP-pulse worth of boost. Capped at 5
// because DP×6 already saturates FIRE_MAX_MS at any reasonable DP.
#define IS_MIN_SEC          0
#define IS_MAX_SEC        600   // 10 minutes
#define IS_DEFAULT_SEC     30   // bench-validated
#define IP_MIN_UNITS        0
#define IP_MAX_UNITS        5
#define IP_DEFAULT_UNITS    1   // first post-idle shot fires with DP × 2

// ============================================================================
// SLOTS
// ============================================================================
#define SLOT_COUNT 3            // 3 stored slots; selector picks 1..3

// ============================================================================
// BATTERY
// ============================================================================
// Voltage divider (V2.1): VBAT --[R16=47k]--+--[R17=10k]-- GND, tap at PIN_VBAT.
// Zener clamp D4 (BZT52C3V3S) was removed in V2.1 — the larger top resistor
// keeps Vadc safely under 3.3 V across all 2S/3S operating ranges.
// Vadc = Vbat * R17/(R16+R17) = Vbat * 10/57
#define VBAT_DIV_NUM   10
#define VBAT_DIV_DEN   57
#define ADC_REF_MV    3300
#define ADC_RESOLUTION 4095   // 12-bit
// Thresholds (mV per cell)
#define CELL_NOMINAL_MV   3700
#define CELL_WARN_MV      3500   // LOW — 6 beeps/min
#define CELL_CRITICAL_MV  3200   // CRITICAL — 12 beeps/min
#define CELL_CUT_MV       3000   // CUT — enter lockout mode (firing block + alarm)
// Cell count detection: 2S (>5.5V & <9V) | 3S (>=9V)
#define V_2S_3S_BOUNDARY_MV 9000
#define V_MIN_VALID_MV      5500
// Sampling
#define BATTERY_SAMPLES     16
#define BATTERY_POLL_MS    500

// ============================================================================
// TRIGGER DEBOUNCE / POLL
// ============================================================================
#define DEBOUNCE_MS         1
#define HALL_POLL_US      500   // analog poll period

// ============================================================================
// WIFI
// ============================================================================
#define WIFI_SSID_DEFAULT   FW_VARIANT_FULL   // BCGA_FCU_PRO
#define WIFI_PASS_DEFAULT   "12345678"
#define WIFI_PASS_MIN_LEN   8

// MOSFET diagnostic test duration (single click pulses for this long)
#define MOS_TEST_DURATION_MS 2000
#define WIFI_AUTO_OFF_MS    (10UL * 60UL * 1000UL)   // 10 minutes

// Inactivity alarm timer. After this much idle time the FCU starts a 6-cycle
// alarm sequence (5 min of beeps + 1 h timer-sleep per cycle), then permanent
// deep sleep. Enable DEEP_SLEEP_DEBUG to shrink the idle timeout to 5 min for
// bench testing — leave commented out in production.
//#define DEEP_SLEEP_DEBUG
#ifdef DEEP_SLEEP_DEBUG
  #define INACTIVITY_TIMEOUT_MS (5UL  * 60UL * 1000UL) //  5 minutes (debug)
#else
  #define INACTIVITY_TIMEOUT_MS (60UL * 60UL * 1000UL) // 60 minutes (prod)
#endif

// Inactivity alarm sequence (constants below are NOT shrunk by DEEP_SLEEP_DEBUG
// — adjust here if you want shorter cycles for bench testing too).
#define ALARM_BURST_DURATION_MS  (5UL  * 60UL * 1000UL) // 5 min of beeps per cycle
#define ALARM_BEEP_INTERVAL_MS   (30UL        * 1000UL) // beep every 30 s
#define ALARM_SLEEP_INTERVAL_MS  (60UL * 60UL * 1000UL) // 1 h between cycles
#define ALARM_MAX_CYCLES         6                       // 6 cycles → ~6 h total

// Battery lockout (PRO only): once cut threshold is hit, firing is blocked and
// a beep fires every LOCKOUT_BEEP_INTERVAL_MS. After LOCKOUT_MAX_BEEPS beeps
// (~30 min) the FCU enters permanent deep sleep to spare what's left of the pack.
#define LOCKOUT_BEEP_INTERVAL_MS (5UL  *        1000UL)  // beep every 5 s
#define LOCKOUT_MAX_BEEPS        360                     // 360 × 5 s ≈ 30 min
#define WIFI_GESTURE_PULL_COUNT 5
#define WIFI_GESTURE_WINDOW_MS  3000
#define DNS_PORT            53
#define HTTP_PORT           80

// ============================================================================
// DEBUG
// ============================================================================
// Auto-start WiFi AP at boot. Comment out for normal operation (button/gesture
// triggered). With this defined, plugging in power immediately brings up the
// AP — useful for benchtop development. The 10-min idle auto-off still applies.
#define WIFI_AUTOSTART_AT_BOOT

#define LOG_ENABLED 1
#if LOG_ENABLED
  #define LOG(...)    Serial.printf(__VA_ARGS__)
  #define LOGLN(s)    Serial.println(s)
#else
  #define LOG(...)    ((void)0)
  #define LOGLN(s)    ((void)0)
#endif

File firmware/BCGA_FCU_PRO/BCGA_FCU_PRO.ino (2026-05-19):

// BCGA FCU PRO — main sketch
// Target: ESP32-C3 SuperMini, Arduino-ESP32 core.
// Variant: PRO (battery sense, WiFi button, dual MOSFET).
// V2.1 dropped the kill-latch circuit; battery protection is now a firmware
// lockout (firing block + audible alarm) — the user must physically disconnect
// the battery to actually preserve it.
//
// Core loop is fully non-blocking: firing state machine, buzzer player,
// WiFi manager, web server, and battery poll all share the same loop().

#include "config.h"
#include "types.h"
#include "selector.h"
#include "buzzer.h"
#include "firing.h"
#include "storage.h"
#include "battery.h"
#include "wifi_manager.h"
#include "web_server.h"
#include "display.h"

#include <esp_sleep.h>

// ── Inactivity alarm state ─────────────────────────────────────────────────
// RTC_DATA_ATTR survives deep sleep, so a multi-cycle alarm sequence can resume
// across timer-wake reboots. Reset to 0/false on a normal (cold or GPIO) wake.
RTC_DATA_ATTR uint8_t  alarmCycleCount = 0;
RTC_DATA_ATTR bool     inAlarmCycle    = false;

namespace {

SlotConfig    activeCfg;
RuntimeState  rs;

// Trigger debounce / edge tracking
bool      trigCurrent  = false;     // logical: true == pressed
bool      trigLastRaw  = false;
uint32_t  trigDebounceUntilMs = 0;

uint32_t  shotsAtLastPersist = 0;
uint32_t  lastShotPersistMs  = 0;

// Activity tracking — last user input of any kind (trigger, selector, WiFi
// button, HTTP request). Drives the inactivity-alarm watchdog.
uint32_t  lastActivityMs        = 0;
uint32_t  trigTestEventCount    = 0;   // increments on every logical edge

// Inactivity alarm timing (volatile within a cycle; cycle count is the
// RTC_DATA_ATTR above)
uint32_t  alarmBurstStartMs  = 0;
uint32_t  lastAlarmBeepMs    = 0;

// Lockout periodic beep (PRO only)
uint32_t  lastLockoutBeepMs  = 0;
uint16_t  lockoutBeepCount   = 0;

// Skip the BOOT/READY beeps and the boot WiFi gesture when waking back into
// the middle of an alarm sequence (no user is around — they'd just delay the
// next beep by a few seconds).
bool      bootIsAlarmResume  = false;

void applySlot(uint8_t idx) {
  storageLoadSlot(idx, activeCfg);
  rs.activeSlot = idx;
  storageSetLastSlot(idx);
  selectorReconfig(activeCfg);
  firingReconfig(activeCfg);
  buzzerPlayCount(idx + 1);
}

bool readTriggerRaw() {
  if (activeCfg.trigMode == SWITCH_DIGITAL) {
    // Default wiring (invertTrig=0): INPUT_PULLUP + switch to GND => LOW when pressed.
    // invertTrig=1 flips the polarity for odd-wired builds.
    bool low = (digitalRead(PIN_TRIG) == LOW);
    return activeCfg.invertTrig ? !low : low;
  }
  int a = analogRead(PIN_TRIG);
  if (a >= activeCfg.hallTrigHigh) return true;
  if (a <= activeCfg.hallTrigLow)  return false;
  return trigCurrent;   // hysteresis band
}

void serviceTrigger() {
  uint32_t now = millis();
  bool raw = readTriggerRaw();
  if (raw != trigLastRaw) {
    trigLastRaw = raw;
    trigDebounceUntilMs = now + DEBOUNCE_MS;
    return;
  }
  if (now < trigDebounceUntilMs) return;
  if (raw == trigCurrent) return;

  trigCurrent = raw;
  lastActivityMs = now;
  // Trigger input also clears any in-progress alarm cycle.
  if (inAlarmCycle) {
    inAlarmCycle    = false;
    alarmCycleCount = 0;
    alarmBurstStartMs = 0;
    lastAlarmBeepMs   = 0;
  }
  trigTestEventCount++;
  FireMode mode = selectorReadMode(activeCfg);

  // Semi ROF cap: swallow the press if we're still inside the cooldown.
  // Always record the release so the edge bookkeeping stays consistent.
  if (trigCurrent && mode == FIRE_SEMI && firingIsSemiBlocked(activeCfg)) {
    return;
  }

  firingOnTriggerEdge(trigCurrent, activeCfg, mode);
}

void serviceTriggerHallPoll() {
  // Hall mode polled at ~2 kHz via micros guard
  static uint32_t lastUs = 0;
  uint32_t u = micros();
  if ((uint32_t)(u - lastUs) < HALL_POLL_US) return;
  lastUs = u;
  serviceTrigger();
}

void persistShotsIfNeeded() {
  uint32_t live = firingShotCount();
  if (live == shotsAtLastPersist) return;
  // throttle NVS writes: every 30s if there's been firing
  if ((uint32_t)(millis() - lastShotPersistMs) < 30000) return;
  storageBumpShots(live - shotsAtLastPersist);
  shotsAtLastPersist = live;
  lastShotPersistMs  = millis();
}

void serviceBattery() {
  // Once lockout has been entered, threshold tracking is moot — the lockout
  // alarm service drives the rest of battery-related behavior until reboot.
  if (batteryInLockout()) return;

  batteryUpdate();

  bool isCut      = batteryCut();
  bool isCritical = batteryCritical();
  bool isLow      = batteryLow();

  // ── Cut: enter lockout (firing block + alarm) ────────────────────────────
  // V2.1 has no kill latch — the battery keeps draining through the regulators
  // until physically disconnected. Lockout signals the user to disconnect.
  if (isCut && !rs.battCut) {
    rs.battCut  = true;
    rs.sysState = SYS_CUT;
    firingForceStop();
    buzzerPlay(BUZZ_BATT_CUT);
    batteryEnterLockout();
    lastLockoutBeepMs = 0;
    lockoutBeepCount  = 0;
    return;
  }

  // ── Periodic low/critical buzzer ─────────────────────────────────────────
  // LOW:      6 beeps/min  → 1 beep every 10000 ms
  // CRITICAL: 12 beeps/min → 1 beep every  5000 ms
  static uint32_t lastBattBeepMs = 0;
  uint32_t beepIntervalMs = 0;

  if (isCritical && !isCut) {
    beepIntervalMs = 5000;
    rs.sysState    = SYS_LOW_BATT;
    rs.battLow     = true;
  } else if (isLow && !isCritical) {
    beepIntervalMs = 10000;
    rs.sysState    = SYS_LOW_BATT;
    rs.battLow     = true;
  } else {
    rs.battLow     = false;
    lastBattBeepMs = 0;   // reset so next warning fires immediately
    if (rs.sysState == SYS_LOW_BATT) rs.sysState = SYS_READY;
  }

  if (beepIntervalMs > 0 && !activeCfg.silentMode) {
    if (lastBattBeepMs == 0 ||
        (uint32_t)(millis() - lastBattBeepMs) >= beepIntervalMs) {
      lastBattBeepMs = millis();
      buzzerPlay(BUZZ_LOW_BATT);
    }
  }
}

// ── Lockout alarm ───────────────────────────────────────────────────────────
// While in battery lockout, beep every 5 s to ask the user to disconnect.
// After LOCKOUT_MAX_BEEPS beeps (~30 min) we run out of useful warning time —
// give up and deep-sleep permanently to spare what charge is left.
// Returns true when the loop should fall through to deep sleep.
bool serviceLockoutAlarm() {
  uint32_t now = millis();
  if (lastLockoutBeepMs == 0 ||
      (uint32_t)(now - lastLockoutBeepMs) >= LOCKOUT_BEEP_INTERVAL_MS) {
    lastLockoutBeepMs = now;
    buzzerPlay(BUZZ_LOW_BATT);
    if (lockoutBeepCount < UINT16_MAX) lockoutBeepCount++;
  }
  return lockoutBeepCount >= LOCKOUT_MAX_BEEPS;
}

// ── Inactivity alarm state machine ─────────────────────────────────────────
// Returns SLEEP_NONE while running normally, SLEEP_TIMER to schedule a
// 1-hour timer-wake (next alarm cycle), or SLEEP_PERMANENT for GPIO-only wake.
enum AlarmSleepCmd : uint8_t { SLEEP_NONE = 0, SLEEP_TIMER, SLEEP_PERMANENT };

AlarmSleepCmd serviceInactivityAlarm() {
  uint32_t now = millis();

  if (!inAlarmCycle) {
    // Normal idle — only enter alarm once we've crossed the inactivity cliff.
    if ((uint32_t)(now - lastActivityMs) < INACTIVITY_TIMEOUT_MS) return SLEEP_NONE;
    inAlarmCycle      = true;
    if (alarmCycleCount == 0) alarmCycleCount = 1;   // first cycle of the run
    alarmBurstStartMs = now;
    lastAlarmBeepMs   = 0;                            // beep immediately
  }

  // We're inside an active beep burst.
  uint32_t elapsed = (uint32_t)(now - alarmBurstStartMs);
  if (elapsed < ALARM_BURST_DURATION_MS) {
    if (lastAlarmBeepMs == 0 ||
        (uint32_t)(now - lastAlarmBeepMs) >= ALARM_BEEP_INTERVAL_MS) {
      lastAlarmBeepMs = now;
      buzzerPlay(BUZZ_INACTIVITY_ALERT);
    }
    return SLEEP_NONE;
  }

  // Beep window done — decide next step.
  if (alarmCycleCount >= ALARM_MAX_CYCLES) {
    // Used up all cycles; permanent sleep, only GPIO can wake us.
    inAlarmCycle    = false;
    alarmCycleCount = 0;
    return SLEEP_PERMANENT;
  }
  // More cycles to go — schedule a 1-hour timer wake; resume on next boot.
  alarmCycleCount++;
  // inAlarmCycle stays true so setup() recognises the wake as an alarm resume
  return SLEEP_TIMER;
}

}  // namespace

// Exported: any user-facing input source calls this to reset the inactivity
// watchdog (and any in-progress alarm cycle).
void noteUserActivity() {
  lastActivityMs = millis();
  if (inAlarmCycle) {
    inAlarmCycle      = false;
    alarmCycleCount   = 0;
    alarmBurstStartMs = 0;
    lastAlarmBeepMs   = 0;
  }
}

// Exported for web_server.cpp — trigger test endpoint (/trigstate).
bool     webServerGetTrigPressed() { return trigCurrent; }
uint32_t webServerGetTrigEvents()  { return trigTestEventCount; }

void setup() {
  // Detect whether we're resuming an in-progress inactivity-alarm cycle
  // (woke from a 1-hour timer sleep, RTC vars preserved). Resume mode skips
  // the boot ritual (no BOOT/READY beep, no WiFi gesture) — there is no user
  // around to interact with the boot.
  esp_sleep_wakeup_cause_t wakeCause = esp_sleep_get_wakeup_cause();
  bootIsAlarmResume = (wakeCause == ESP_SLEEP_WAKEUP_TIMER) &&
                      inAlarmCycle &&
                      (alarmCycleCount < ALARM_MAX_CYCLES);
  if (!bootIsAlarmResume) {
    inAlarmCycle    = false;
    alarmCycleCount = 0;
  }

  Serial.begin(115200);
  delay(50);
  LOG("\n%s %s (%s)%s\n", FW_NAME, FW_VERSION, FW_VARIANT,
      bootIsAlarmResume ? " [alarm resume]" : "");

  // I/O
  pinMode(PIN_TRIG, INPUT_PULLUP);

  storageBegin();
  uint8_t lastSlot = storageGetLastSlot();
  storageLoadSlot(lastSlot, activeCfg);

  displayInit();
  displaySetSlot(lastSlot, activeCfg.solenoidCount);

  buzzerBegin();
  firingBegin(activeCfg);
  selectorBegin(activeCfg);
  batteryBegin();
  wifiManagerBegin();

  rs.activeSlot = lastSlot;
  rs.sysState   = SYS_READY;
  rs.currentMode = selectorReadMode(activeCfg);

  if (!bootIsAlarmResume) {
    buzzerPlay(BUZZ_BOOT);
    if (storageWasFirstBoot()) {
      // First-ever boot (NVS just initialized) — follow BUZZ_BOOT with BUZZ_READY
      // so the user can recognize a fresh unit from a normal power-up.
      uint32_t t = millis();
      while (buzzerBusy() && (uint32_t)(millis() - t) < 800) { buzzerUpdate(); }
      delay(200);
      buzzerPlay(BUZZ_READY);
    }
  }
  shotsAtLastPersist = 0;
  lastShotPersistMs  = millis();

  LOG("Active slot: %u (%s)\n", lastSlot, activeCfg.name);

  // ── Boot gesture: trigger 5 s → WiFi AP, trigger + WiFi button 30 s →
  // factory reset. Loop runs only while the trigger is being held — a normal
  // boot (no press) skips it entirely so WiFi auto-start happens immediately.
  // After 5 s of continuous trigger hold the user gets a countdown chirp every
  // 5 s; release between 5 s and 30 s starts the WiFi AP. Factory reset only
  // fires if the WiFi button was held continuously for the full 30 s as well.
  // Skipped on alarm resume — no user is present.
  if (!bootIsAlarmResume && digitalRead(PIN_TRIG) == LOW) {
    const uint32_t WIFI_HOLD_MS      = 5000;
    const uint32_t FACTORY_HOLD_MS   = 30000;
    const uint32_t COUNTDOWN_BEEP_MS = 5000;
    uint32_t trigHoldStart = millis();
    uint32_t btnHoldStart  = (digitalRead(PIN_WIFI_BTN) == LOW) ? trigHoldStart : 0;
    uint32_t lastBeepAt    = trigHoldStart;

    while (digitalRead(PIN_TRIG) == LOW) {
      uint32_t held = (uint32_t)(millis() - trigHoldStart);
      bool btnPressed = (digitalRead(PIN_WIFI_BTN) == LOW);

      // Track continuous WiFi-button hold separately — factory gesture
      // requires both trigger AND button held for the full window.
      if (btnPressed && btnHoldStart == 0) btnHoldStart = millis();
      else if (!btnPressed)                btnHoldStart = 0;

      if (held >= WIFI_HOLD_MS &&
          (uint32_t)(millis() - lastBeepAt) >= COUNTDOWN_BEEP_MS) {
        buzzerPlayCount(1);
        lastBeepAt = millis();
      }

      bool factoryHoldReady =
          (held >= FACTORY_HOLD_MS) &&
          btnHoldStart != 0 &&
          ((uint32_t)(millis() - btnHoldStart) >= FACTORY_HOLD_MS);
      if (factoryHoldReady) {
        LOGLN("Factory reset gesture detected — wiping NVS");
        buzzerPlay(BUZZ_TEST);   // 1 s sustained tone confirms the reset
        uint32_t bt = millis();
        while (buzzerBusy() && (uint32_t)(millis() - bt) < 1500) buzzerUpdate();
        storageFactoryReset();
        delay(200);
        ESP.restart();
      }
      buzzerUpdate();
    }

    // Released — start WiFi AP if the trigger hold passed the WiFi threshold.
    if ((uint32_t)(millis() - trigHoldStart) >= WIFI_HOLD_MS) {
      wifiStart();
      buzzerPlayCount(3);
      uint32_t bt = millis();
      while (buzzerBusy() && (uint32_t)(millis() - bt) < 1500) buzzerUpdate();
    }
  }

  // On a normal boot we treat boot itself as activity (so the alarm doesn't
  // fire ~60 min later if the user just powered on and walked away — they did
  // touch it). On alarm resume, leave lastActivityMs at 0 so the burst window
  // starts firing beeps immediately.
  if (!bootIsAlarmResume) {
    lastActivityMs = millis();
  } else {
    alarmBurstStartMs = millis();
    lastAlarmBeepMs   = 0;
  }

#ifdef WIFI_AUTOSTART_AT_BOOT
  if (!bootIsAlarmResume) {
    LOGLN("WIFI_AUTOSTART_AT_BOOT defined -> starting AP now");
    wifiStart();
  }
#endif
}

void loop() {
  // 1) Trigger input — always serviced; trigger pulls clear lockout? No, only
  // a reboot (battery reconnect) clears lockout. But a trigger pull still
  // counts as activity for the inactivity watchdog.
  if (activeCfg.trigMode == SWITCH_HALL) {
    serviceTriggerHallPoll();
  } else {
    serviceTrigger();
  }

  // 2) Lockout: skip firing & most services. Beep periodically; after the
  // configured warning window, deep-sleep permanently to spare the pack.
  if (batteryInLockout()) {
    bool exhausted = serviceLockoutAlarm();
    buzzerUpdate();
    wifiManagerUpdate();   // leave WiFi serving so a connected client sees status
    if (exhausted) {
      if (wifiActive()) wifiStop();
      buzzerStop();
      displaySleep();
      esp_deep_sleep_enable_gpio_wakeup(1ULL << PIN_TRIG, ESP_GPIO_WAKEUP_GPIO_LOW);
      esp_deep_sleep_start();   // never returns
    }
    return;
  }

  // 3) Selector — track changes for buzzer feedback. Mode change counts as
  // user activity for the inactivity watchdog.
  static FireMode lastMode = FIRE_SAFE;
  FireMode mode = selectorReadMode(activeCfg);
  if (mode != lastMode) {
    lastMode = mode;
    rs.currentMode = mode;
    if (!activeCfg.silentMode) buzzerPlay(BUZZ_MODE_CHANGE);
    noteUserActivity();
  }

  // 4) Firing engine
  firingUpdate(activeCfg, mode);

  // 5) Buzzer player
  buzzerUpdate();

  // 6) Battery
  serviceBattery();

  // 7) WiFi (handles DNS + HTTP when active)
  wifiManagerUpdate();

  // 8) MOSFET diagnostic test scheduler (web /test → 2s pulse)
  mosTestService();

  // 9) Persist shot counter occasionally
  persistShotsIfNeeded();

  // 10) Inactivity alarm watchdog. After INACTIVITY_TIMEOUT_MS of no user
  // input, the FCU starts a 6-cycle alarm: 5 min of beeps every 30 s, then
  // 1 h of timer-deep-sleep, repeat. After the last cycle we deep-sleep
  // permanently (only a trigger pull wakes the MCU, via full reboot).
  AlarmSleepCmd sleepCmd = serviceInactivityAlarm();
  if (sleepCmd != SLEEP_NONE) {
    if (wifiActive()) wifiStop();
    buzzerStop();
    displaySleep();
    esp_deep_sleep_enable_gpio_wakeup(1ULL << PIN_TRIG, ESP_GPIO_WAKEUP_GPIO_LOW);
    if (sleepCmd == SLEEP_TIMER) {
      esp_sleep_enable_timer_wakeup((uint64_t)ALARM_SLEEP_INTERVAL_MS * 1000ULL);
    }
    esp_deep_sleep_start();
    // Never returns.
  }
}

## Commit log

2026-04-16 docs: README completo bilíngue PT/EN
    - Estrutura do repo (MotherBoard, DBA, DBB) e licença GPL v3
    - Links destacados para bcgaairsoft.com/fcu/str (mais infos, kit físico)
    - Instruções de uso: download via site, git clone ou compra
    - Marca firmware como "em breve"
2026-04-17 firmware: split unified V2 into dedicated PRO and STR sketches
    Adds three Arduino sketch folders under firmware/:
    - BCGA_FCU_V2/ unified source (preserved as-is)
    - BCGA_FCU_PRO/ Pro-only build, no #ifdef BCGA_PRO toggles
    - BCGA_FCU_STR/ Starter-only build, S8PA only, no battery/MOS swap/SOL2
    [BCGA_FCU_PRO.ino, BCGA_FCU_STR.ino, battery.cpp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]
2026-04-19 firmware: STR gains D8PA parity with PRO + shared deep-sleep debug switch + user manual
    STR now supports both S8PA and D8PA firing modes (PIN_MOS_2 wired, full 4-state
    engine ported from PRO, web UI radio cards + DN/DL/MOS-swap fields). Both PRO
    and STR get a DEEP_SLEEP_DEBUG preprocessor switch that cuts the 60 min idle
    timeout to 5 min for bench testing. Adds firmware/MANUAL.md — bilingual PT/EN
    usage guide covering first boot, WiFi gestures, slots, timings, selector modes,
    Hall calibration, diagnostics, and variant differences.
    [BCGA_FCU_PRO.ino, BCGA_FCU_STR.ino, battery.cpp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]
2026-04-19 docs: split manual into PT/EN + PDFs, refresh README with firmware links
    Splits the bilingual MANUAL.md into MANUAL_PT.md and MANUAL_EN.md so each
    language reads cleanly on its own. Reorients the content around practical
    tuning: each timing (DN/DR/DP/DL) now has a "bigger/smaller -> effect" table,
    plus a recommended tuning workflow and step-by-step Hall trigger and Hall
    selector calibration procedures. Ships matching MANUAL_PT.pdf / MANUAL_EN.pdf
    for offline use. Updates the top-level README to reflect that firmware is
    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
2026-04-19 docs: rename DL→DB (Trigger Debounce, units), add competitive comparison, split README into EN/PT
    - DB replaces DL across all 4 user-facing docs; 1 unit = 0.1 ms, range 20–800 units, default 100 units. Physical behavior unchanged; note in manuals explains the rename. Firmware web UI still uses DL/ms — to be updated in a follow-up.
    - Manuals gain a new section 15 comparing BCGA FCU against REV3 / BLINC / TITAN II with 10 advantages and 4 honest limitations.
    - README.md is now English-only; LEIA-ME.md is the new PT-BR mirror at repo root. Manuals remain bilingual as separate files under firmware/.
2026-04-19 docs: fix S8PA/D8PA engine classification
    Previous docs wrongly listed F2 under S8PA and JACK/Backdraft under D8PA. Per the engine reference, F2 / Fusion Engine / PULSAR D are dual-solenoid (D8PA), while JACK / F1 / INFERNO / PULSAR S are single-solenoid (S8PA). Also replaced bare "Pulsar" (ambiguous) with explicit PULSAR S or PULSAR D and dropped the misleading "Jack-style" archetype from the D8PA defaults block.
2026-04-19 docs: add Quick Start FPS workflow, fix comparison inaccuracies, gas→air
    - Insert Quick Start section (manual §3) walking users PSI→DP→chrono before timings
    - Rewrite §16.1 point 10: commercial FCUs use dedicated cables, not adapter harnesses
    - Nuance §16.1 point 2: REV3 dual exposes 3 timings (not 1); no commercial FCU has dedicated post-shot debounce
    - Add Gorilla FCU column to §16.3 comparison table (native single+dual, separate SEMI/AUTO dwells)
    - Clarify single/dual split per engine (BLINC single only, PULSAR S/D split, JACK single)
    - Replace "gas"/"gás" with "air"/"ar" throughout (HPA = compressed air)
    - Renumber manual sections 3–15 → 4–16 after Quick Start insertion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
2026-04-19 docs: HPA engines not gearboxes, swap §2/§3 so Quick Start leads, drop DL rename notes + PDFs
    - Call S8PA/D8PA/F2/PULSAR "HPA engines", reserving "gearbox" for the physical V2/V3 shell where the engine mounts
    - Swap manual sections: Quick Start is now §2 (first thing new users read), The 4 timings guide becomes §3
    - Remove the transitional DL→DB rename notes from both manuals
    - Regenerate MANUAL_EN.pdf / MANUAL_PT.pdf to reflect the above
2026-04-19 docs: add FCU Config Helper V2 React source
    Data-driven brand-agnostic tuning wizard used at bcgaairsoft.com/fcu/wizard.
    14-step flow covering engine selection, chrono sweep at 80/100/120 psi,
    hopup reading, iterative DP tuning, and deep-dive explanation for each of
    the 4 timings (DN, DR, DP, DB) with cross-brand name mapping (PolarStar
    F2, Wolverine INFERNO, GATE PULSAR D).
    Added under docs/wizard-v2-source/ alongside the existing static HTML
    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
2026-04-27 firmware: V2.1 latch removal + inactivity alarm + OLED + DB units
    PRO V2.1 dropped the kill-latch circuit (Q1/Q3/Q5). VBAT now goes
    straight from F1 to SYS_VCC; firmware no longer controls power.
    Battery protection is now a software lockout (firing block + audible
    alarm) — physical disconnect is required to actually preserve the pack.
    Battery & lockout (PRO):
    - Drop PIN_LATCH/batteryKillLatch from config.h, battery.{h,cpp},
    BCGA_FCU_PRO.ino. GPIO 21 freed (commented for history).
    - Cut threshold (3.0 V/cell) now calls batteryEnterLockout(): firing
    permanently disabled, BUZZ_LOW_BATT every 5 s.
    - After LOCKOUT_MAX_BEEPS (360 ~= 30 min) the FCU enters permanent
    deep sleep; only a trig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
    [BCGA_FCU_PRO.ino, BCGA_FCU_STR.ino, battery.cpp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]
2026-04-27 docs: V2.1 latch removal + inactivity alarm
    README/LEIA-ME: replace kill-latch limitation with no-auto-cutoff +
    new battery-drain warning (~12-18 mA regulators); hardware spec rows
    for inactivity alarm and PRO battery management.
    MANUAL_EN/PT §14: rewrite as "Deep sleep, inactivity alarm and debug
    mode" — adds 6-cycle alarm sequence, regulator drain note, battery
    lockout subsection (PRO only, no auto cut-off).
    §15 STR vs PRO: kill latch X on PRO V2.1 (replaced by lockout) +
    inactivity alarm + battery lockout rows.
    §16.2/16.3: factual update — no auto cut-off, 12-18 mA regulator
    drain.
    PDFs regenerated. Wide table cells were shortened to work around a
    markdown-pdf hang (CSS+layout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
2026-04-28 firmware: V2.1 buzzer refactor (active magnetic, digital drive)
    V2.1 swapped the passive piezo + Q6 driver + flyback diode for an
    FUET-9650B-3V active magnetic buzzer (3 kHz oscillator built in)
    wired through R18=47Ohm straight to PIN_BUZZER. Frequency is fixed
    by the part — firmware just toggles the GPIO on/off.
    - buzzer.{h,cpp} (PRO + STR): drop LEDC PWM. struct Step is now
    {bool on, uint16_t durMs}. PATTERNS array rewritten so every event
    is recognisable by beep count and duration alone (BOOT 1x80ms,
    READY 1x200ms, BATT_CUT 3 longs + terminal, etc.). buzzerBegin /
    startStep / buzzerStop / buzzerPlayCount all switched to
    digitalWrite.
    - config.h (PRO + STR): drop LEDC_BUZZER_{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
    [buzzer.cpp, config.h, wifi_manager.cpp]
2026-04-28 firmware: V2.1 BATT_SENSE divider update (R16 33k -> 47k, drop D4)
    V2.1 swapped R16 from 33 kOhm to 47 kOhm and removed the BZT52C3V3S
    zener clamp (D4). The larger top resistor keeps Vadc safely under
    3.3 V across the full 2S/3S operating range without needing the
    clamp:
    2S full 8.4 V -> 1.47 V (ADC ~1828)
    3S full 12.6 V -> 2.21 V (ADC ~2742)
    3S overcharge 13.2 V -> 2.32 V
    Update VBAT_DIV_DEN 43 -> 57 (numerator stays 10) and the explanatory
    comment. battery.cpp already reads via the macros — no logic change.
    Cell-mV thresholds (CELL_WARN/CRITICAL/CUT) unchanged: they're per-
    cell millivolts and the divider math handles the conversion.
    Calibration note: 1 % resistors stack to ~2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
    [config.h]
2026-05-19 firmware: V2.1.1 anti-stiction + config lock + factory reset gesture
    Anti-stiction (Polarstar iS/iP): new SlotConfig fields. After IS seconds
    idle, the next shot's DP is multiplied by (1 + IP) to break o-ring
    stiction. Defaults IS=30s, IP=1 (first post-idle shot fires with 2x DP).
    Config LOCK: device-wide password gates slot save/switch/reset.
    storageHasCfgPwd/Get/Set/Locked + sessionUnlocked runtime cache.
    New /cfglock GET+POST endpoint with set/lock/unlock/clear actions.
    Boot gesture: trigger 5s -> WiFi AP (chirp every 5s after 5s held);
    trigger 30s -> factory reset on STR; PRO requires trigger + WiFi
    button held 30s. Released between 5-30s still brings up WiFi.
    Defaults rebench: DN=DR=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
    [BCGA_FCU_PRO.ino, BCGA_FCU_STR.ino, config.h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]
2026-05-19 tooling: extract web UI to firmware/web_ui_dev/ + build_web_ui.py
    Edit-friendly source split: style.css + app.js + index_str.html +
    index_pro.html live in firmware/web_ui_dev/. mock.js stubs the ESP
    endpoints so you can preview the UI in a browser without flashing.
    tools/build_web_ui.py inlines style.css into <style>, app.js into
    <script>, strips the mock <script src="mock.js">, wraps in a C++ raw
    string with a DO-NOT-EDIT header, and writes firmware/BCGA_FCU_<V>/
    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
2026-05-19 docs: standalone setup wizard + site refresh prompt
    docs/wizard/{index.html, wizard.css, wizard.js}: standalone planning
    wizard (5 steps: engine pick -> FPS target -> chrono result ->
    fine-tune -> summary). Pre-flash educational tool, separate from the
    runtime UI that ships on the ESP. Same defaults/ranges/labels as the
    current firmware so users plan with values they can actually apply.
    docs/wizard/PROMPT_SITE_UPDATE.md: brief for the next session in the
    bcgaairsoft.com site repo. Captures the V2.1.1 firmware delta the
    site wizard needs to absorb (new defaults, DB range, anti-stiction,
    selector input dropdown, language default flip) plus the 3-menu
    landing redesign (Learn / Configure / Trou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
2026-06-13 hardware: update DBA/DBB/FCU STR fab files to V1.0 (2026-06-13)
    Refresh BOM, CPL, Gerber, schematic PDF and STEP for all three
    boards from the 2026-06-13 fab package. Add Assembly_STEP/ with
    full-assembly STEP models (DBA, DBB, FCU PRO, FCU STR).
    [BOM BCGA_FCU_STR.xlsx, BOM DBA.xlsx, BOM DBB.xlsx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]
2026-06-13 hardware: replace FCU STR motherboard fab files with correct V1.0 set
    Update BOM, CPL (pick-and-place), Gerber, and schematic PDF with the
    corrected V1.0 export (2026-06-13). STEP unchanged (identical bytes).
    [BOM BCGA_FCU_STR.xlsx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]
2026-07-02 docs: add PCB trace error notice to fab file folders
    Warns downloaders that a trace error was found and a fix/updated
    files are in progress, until corrected fab files are re-uploaded.
